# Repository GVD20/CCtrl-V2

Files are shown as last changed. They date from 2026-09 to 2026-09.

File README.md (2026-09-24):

<h1 align="center">CCtrl-V2</h1>

<p align="center">
  <strong>六轴机械臂关节空间遥操作器</strong><br>
  前两连杆等长 · 支持 XZY/ZXZ 腕部姿态表示
</p>

<p align="center">
  <a href="README.md">简体中文</a> · <a href="README_EN.md">English</a>
</p>

<p align="center">
  
  
  
</p>

<p align="center">
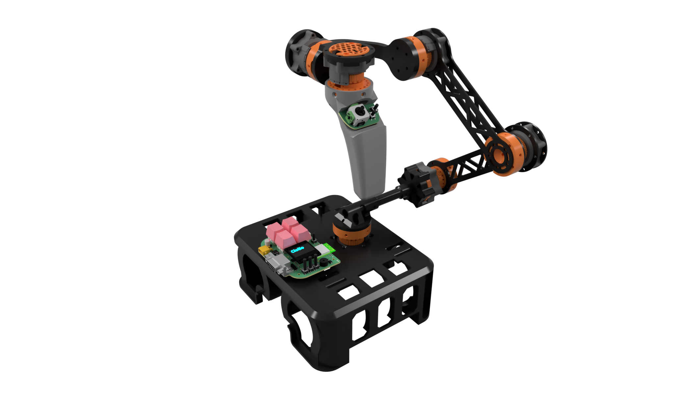
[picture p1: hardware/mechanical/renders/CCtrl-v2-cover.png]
CCtrl-V2 模型效果图
  
</p>

CCtrl-V2 以六个磁编码器采集 A1–A6 关节角，手柄节点采集摇杆、按键与磁感应扳机。ESP32-S3 主控负责节点轮询、校准、OLED 菜单、腕部姿态表示转换与 RS232 输出。本仓库包含嵌入式固件、四板 JLCEDA Pro 工程、机械模型、用户文档和调试工具。

<h5>▌快速入口</h5>

| 模块 | 中文 | English |
|---|---|---|
| 用户手册 | [CCtrl-v2_User_Manual_ZHCN](docs/CCtrl-v2_User_Manual_ZHCN.md) | [CCtrl-v2_User_Manual_EN](docs/CCtrl-v2_User_Manual_EN.md) |
| 嵌入式固件 | [CCtrl-v2_Embedded_Firmware_ZHCN](docs/CCtrl-v2_Embedded_Firmware_ZHCN.md) | [CCtrl-v2_Embedded_Firmware_EN](docs/CCtrl-v2_Embedded_Firmware_EN.md) |
| 硬件工程资料 | [CCtrl-v2_Hardware_Engineering_ZHCN](docs/CCtrl-v2_Hardware_Engineering_ZHCN.md) | [CCtrl-v2_Hardware_Engineering_EN](docs/CCtrl-v2_Hardware_Engineering_EN.md) |
| 机械模型 | [CCtrl-v2_Mechanical_Models_ZHCN](docs/CCtrl-v2_Mechanical_Models_ZHCN.md) | [CCtrl-v2_Mechanical_Models_EN](docs/CCtrl-v2_Mechanical_Models_EN.md) |
| 调试工具 | [CCtrl-v2_Debug_Tools_ZHCN](docs/CCtrl-v2_Debug_Tools_ZHCN.md) | [CCtrl-v2_Debug_Tools_EN](docs/CCtrl-v2_Debug_Tools_EN.md) |

专题文档：[节点协议](docs/PROTOCOL_V2.md) · [RS232 串口协议](docs/SERIAL_PROTOCOL_ZHCN.md) · [六轴校准](docs/CALIBRATION_ZHCN.md) · [USB 调试协议](docs/USB_DEBUG_ZHCN.md)

<h5>▌项目概览</h5>

- ESP32-S3 主板通过 250000 bps 菊花链串口连接六个 Encoder 节点与一个 Handle 节点；ATmega328P 与 CH32V006 提供节点固件实现。
- 六路 AS5600 编码器按物理链路顺序映射到 A1–A6。Handle 提供摇杆、S1–S3 按键和磁感应扳机，扳机行程生成 S4。
- RS232 约 30 Hz 输出固定 39 字节 RoboMaster `0x0302` 帧；USB CDC 用于手动启动的本地调试与校准。
- OLED 菜单提供六轴校准、休息位姿保护及腕部 XZY/ZXZ 表示选择。
- 控制端输出关节计数与状态；机械臂接收端实现目标机构的尺寸、零位、方向与运动控制映射。

<h5>▌与原版 CCtrl 的关系</h5>

本项目继承 [GVD20/CCtrl](https://github.com/GVD20/CCtrl) 的 MIT 许可、主板设计和 RoboMaster `0x0302` 外层帧，重构了机构构型、节点链路与载荷语义。

| 项目 | 原版 CCtrl | CCtrl-V2 |
|---|---|---|
| 机构与传感 | 三路编码器、IMU 的空间交互机构 | 面向前两段连杆等长机械臂的六关节编码器机构 |
| 节点链路 | 原版节点协议 | Daisy-Chain Protocol V2，支持 Encoder 与 Handle 节点 |
| 对外数据 | 融合位置、姿态与滚轮等数据 | 六关节计数、手柄输入及状态；[30 字节 V2 载荷](docs/SERIAL_PROTOCOL_ZHCN.md) |
| 上位机 | WebXR 等原版工作流 | RS232 通道监视器与本地 USB 调试校准页 |

两版共用 `0x0302` 命令号；接收端按对应版本的载荷格式解析。

<h5>▌目录结构</h5>

```text
.
├─ include/
├─ lib/
├─ src/
│  ├─ master/
│  ├─ node_avr/
│  ├─ node_ch32v006/
│  ├─ shared/
│  └─ ui_runtime/
├─ test/
├─ tools/
│  ├─ rs232_channel_monitor.py
│  └─ usb_robot_debug/
├─ docs/
├─ hardware/
│  ├─ electronics/jlc_eda_pro/
│  └─ mechanical/
├─ platformio.ini
├─ LICENSE
├─ README.md
└─ README_EN.md
```

<h5>▌固件构建</h5>

```bash
pio run -e master_esp32s3
pio run -e encoder_node_atmega328p
pio run -e encoder_node_ch32v006
```

CH32V006 节点按上电时检测到的传感器进入 Encoder 或 Handle 模式；ATmega328P 节点用于 Encoder。各环境的编程协议见[嵌入式固件](docs/CCtrl-v2_Embedded_Firmware_ZHCN.md)。

<h5>▌上位机与调试</h5>

```bash
python tools/rs232_channel_monitor.py
python tools/usb_robot_debug/server.py
```

- [RS232 通道监视器](tools/RS232_CHANNEL_MONITOR_ZHCN.md)：显示 39 字节业务帧中的六轴、状态、按键和手柄数据，并绘制曲线、导出 CSV。
- [USB 调试页面](tools/usb_robot_debug/README.md)：显示原始采样、XZY/ZXZ、诊断和校准配置；业务帧仍由 RS232 输出。

<h5>▌硬件资料</h5>

电子设计以包含主板、手柄模块 v2、带滑环的编码器节点板及滑环电刷的 [JLCEDA Pro 工程](hardware/electronics/jlc_eda_pro/CCtrl-v2.epro2)提供。机械资料包含[完整装配 STEP](hardware/mechanical/cad/CCtrl-v2-assembly.step)、[局部改进替换件 STEP](hardware/mechanical/cad/CCtrl-v2-replacement-parts.step)与透明封面图。

<h5>▌PIO 库依赖</h5>

- `encoder_node_atmega328p`：`robtillaart/AS5600`
- `master_esp32s3`：`frankboesing/FastCRC`、`olikraus/U8g2`
- 本地库：`lib/WouoUiLiteGeneralBridge`、`lib/WouoUiLiteGeneralOfficial`

<h5>▌验证</h5>

三个 PlatformIO 固件环境均完成构建；协议解析、休息位姿、腕部转换和 USB 帧解析通过源码测试。

<h5>▌UI 框架说明</h5>

项目 UI 实现参考并适配了 [RQNG/WouoUI](https://github.com/RQNG/WouoUI)。

<h5>▌开源协议</h5>

本项目采用 MIT License，详见 [LICENSE](LICENSE)。

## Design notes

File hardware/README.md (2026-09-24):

# CCtrl-V2 硬件资料

[用户手册](../docs/CCtrl-v2_User_Manual_ZHCN.md) · [返回首页](../README.md)

## 电子工程

[CCtrl-v2.epro2](electronics/jlc_eda_pro/CCtrl-v2.epro2) 是本版的 JLCEDA Pro 电子设计工程。包内包含主板、Handle_node_v2、Encoder_node_v3 和 Encoder_brush 四块板的原理图及 PCB 文档。主板延续原版主控方案；制造文件可在 JLCEDA Pro 中导出。

工程包含封装、引脚、电源、菊花链方向、滑环与电刷通道、板间连接等电子设计信息。

## 机械工程

[完整装配 STEP](mechanical/cad/CCtrl-v2-assembly.step) 提供整体模型；[替换件 STEP](mechanical/cad/CCtrl-v2-replacement-parts.step) 包含部分改进零件，用于替换完整模型中的对应零件。两份模型的关系见[机械说明](mechanical/README.md)。

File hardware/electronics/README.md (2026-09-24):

# 电子工程

[JLCEDA Pro 原生工程](jlc_eda_pro/CCtrl-v2.epro2)包含四块板：主板、手柄模块 v2、带滑环的编码器节点板，以及滑环电刷板。JLCEDA Pro 提供工程查看和制造文件导出功能。

主控、编码器和手柄固件入口见[用户手册](../../docs/CCtrl-v2_User_Manual_ZHCN.md)。原理图与 PCB 包含板层、器件、连接器、滑环走线和供电设计。

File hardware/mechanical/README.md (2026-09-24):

# 机械模型

| 文件 | 内容 |
|---|---|
| [CCtrl-v2-assembly.step](cad/CCtrl-v2-assembly.step) | 完整装配模型 |
| [CCtrl-v2-replacement-parts.step](cad/CCtrl-v2-replacement-parts.step) | 对主模型中部分零件的改进版本，涉及内部走线和稳定性 |
| [CCtrl-v2-cover.png](renders/CCtrl-v2-cover.png) | 带透明通道的效果图 |

替换件 STEP 用于更新完整装配中的部分零件。零件对应关系由两份 STEP 的几何形状与装配位置体现；封面图展示整体外观。结构说明见[机械模型](../../docs/CCtrl-v2_Mechanical_Models_ZHCN.md)。

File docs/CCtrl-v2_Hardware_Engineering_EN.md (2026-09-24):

# CCtrl-V2 Hardware Engineering

[ZHCN](CCtrl-v2_Hardware_Engineering_ZHCN.md) | [EN](CCtrl-v2_Hardware_Engineering_EN.md)

This page lists the CCtrl-V2 electronics project and its four board designs.

## Main files and directories

- [JLCEDA Pro project](../hardware/electronics/jlc_eda_pro/CCtrl-v2.epro2): schematic and PCB project.
- [Electronics guide](../hardware/electronics/README.md): project format and board list.
- [Hardware index](../hardware/README.md): electronics and mechanical assets.

## Project contents

| Board | Project name | Role |
|---|---|---|
| Main board | `CC_ESP32main` | ESP32-S3 master and external interfaces |
| Handle module v2 | `Handle_node_v2` | Joystick, buttons, magnetic trigger |
| Encoder node with slip ring | `Encoder_node_v3` | Joint-angle sampling and daisy-chain relay |
| Slip-ring brush | `Encoder_brush` | Electrical connection across a rotating joint |

The electronics are provided as a native JLCEDA Pro project, from which manufacturing outputs are exported. The main board retains the original CCtrl design basis; the nodes and handle match the six-axis mechanism and V2 firmware.

## Related documents

- [User manual](CCtrl-v2_User_Manual_EN.md)
- [Embedded firmware](CCtrl-v2_Embedded_Firmware_EN.md)
- [Mechanical models](CCtrl-v2_Mechanical_Models_EN.md)

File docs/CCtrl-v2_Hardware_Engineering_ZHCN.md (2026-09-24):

# CCtrl-V2 硬件工程资料

[ZHCN](CCtrl-v2_Hardware_Engineering_ZHCN.md) | [EN](CCtrl-v2_Hardware_Engineering_EN.md)

本页汇总 CCtrl-V2 的电子工程文件及四块板的项目组成。

## 主要文件与目录

- [JLCEDA Pro 工程](../hardware/electronics/jlc_eda_pro/CCtrl-v2.epro2)：原理图与 PCB 的项目文件。
- [电子工程说明](../hardware/electronics/README.md)：工程格式与板卡列表。
- [硬件资料入口](../hardware/README.md)：电子与机械资料目录。

## 工程组成

| 板卡 | 项目内名称 | 用途 |
|---|---|---|
| 主板 | `CC_ESP32main` | ESP32-S3 主控与对外接口 |
| 手柄模块 v2 | `Handle_node_v2` | 摇杆、按键与磁感应扳机 |
| 带滑环的编码器节点板 | `Encoder_node_v3` | 关节角采集与菊花链转发 |
| 滑环电刷 | `Encoder_brush` | 旋转关节的电气连接 |

电子设计以 JLCEDA Pro 原生项目提供，制造输出由该工程导出。主板沿用原版 CCtrl 的设计基础，节点与手柄对应六轴机构及 V2 固件。

## 相关文档

- [用户手册](CCtrl-v2_User_Manual_ZHCN.md)
- [嵌入式固件](CCtrl-v2_Embedded_Firmware_ZHCN.md)
- [机械模型](CCtrl-v2_Mechanical_Models_ZHCN.md)

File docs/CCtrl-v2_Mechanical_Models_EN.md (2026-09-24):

# CCtrl-V2 Mechanical Models

[ZHCN](CCtrl-v2_Mechanical_Models_ZHCN.md) | [EN](CCtrl-v2_Mechanical_Models_EN.md)

This page lists the CCtrl-V2 assembly model, improved replacement parts, and cover render.

## Main files and directories

| File | Contents |
|---|---|
| [CCtrl-v2-assembly.step](../hardware/mechanical/cad/CCtrl-v2-assembly.step) | Full assembly model |
| [CCtrl-v2-replacement-parts.step](../hardware/mechanical/cad/CCtrl-v2-replacement-parts.step) | Improved parts from the main model, including internal cable routing and stability changes |
| [CCtrl-v2-cover.png](../hardware/mechanical/renders/CCtrl-v2-cover.png) | Transparent-background cover render |
| [Mechanical assets guide](../hardware/mechanical/README.md) | Relationship between the model files |

## Model relationship

The full-assembly STEP describes the six-axis controller mechanism. The replacement-parts STEP contains revised versions of selected assembly parts; correspondence follows their geometry and position in the two STEP files. The cover PNG depicts the exterior and retains an alpha channel.

Joints A1–A6 correspond to the six Encoder channels, and the first two links are equal in length. The receiving robot controller maps joint counts to its own link dimensions and kinematics.

## Related documents

- [User manual](CCtrl-v2_User_Manual_EN.md)
- [Hardware engineering](CCtrl-v2_Hardware_Engineering_EN.md)

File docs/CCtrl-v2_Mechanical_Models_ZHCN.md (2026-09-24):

# CCtrl-V2 机械模型

[ZHCN](CCtrl-v2_Mechanical_Models_ZHCN.md) | [EN](CCtrl-v2_Mechanical_Models_EN.md)

本页汇总 CCtrl-V2 的机械装配、改进替换件及外观图。

## 主要文件与目录

| 文件 | 内容 |
|---|---|
| [CCtrl-v2-assembly.step](../hardware/mechanical/cad/CCtrl-v2-assembly.step) | 完整装配模型 |
| [CCtrl-v2-replacement-parts.step](../hardware/mechanical/cad/CCtrl-v2-replacement-parts.step) | 主模型中部分零件的改进版本，包含内走线与稳定性设计 |
| [CCtrl-v2-cover.png](../hardware/mechanical/renders/CCtrl-v2-cover.png) | 透明背景渲染主图 |
| [机械资料说明](../hardware/mechanical/README.md) | 模型文件关系 |

## 模型关系

完整装配 STEP 描述六轴控制器的整体结构。替换件 STEP 包含用于更新完整装配中对应零件的局部改进模型；替换关系由两份 STEP 的零件几何与装配位置确定。封面图展示外观，透明通道保留在 PNG 中。

控制器的关节 A1–A6 与六路 Encoder 数据对应，前两段连杆等长。接收端按目标机械臂的实际连杆尺寸建立运动学映射；控制器固件输出关节计数。

## 相关文档

- [用户手册](CCtrl-v2_User_Manual_ZHCN.md)
- [硬件工程资料](CCtrl-v2_Hardware_Engineering_ZHCN.md)

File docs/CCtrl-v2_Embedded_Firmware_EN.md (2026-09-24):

# CCtrl-V2 Embedded Firmware

[ZHCN](CCtrl-v2_Embedded_Firmware_ZHCN.md) | [EN](CCtrl-v2_Embedded_Firmware_EN.md)

This page maps the CCtrl-V2 firmware environments, source directories, and runtime roles.

## Main files and directories

| Entry | Contents |
|---|---|
| [platformio.ini](../platformio.ini) | Three PlatformIO environments, dependencies, upload protocols |
| [src/master](../src/master) | ESP32-S3 master, calibration, wrist conversion, USB debugging |
| [src/node_avr](../src/node_avr) | ATmega328P Encoder node |
| [src/node_ch32v006](../src/node_ch32v006) | CH32V006 Encoder/Handle node |
| [src/shared](../src/shared) | Daisy-chain frames, CRC, shared protocol definitions |
| [src/ui_runtime](../src/ui_runtime) | OLED UI runtime |
| [include](../include), [lib](../lib) | UI configuration, business interfaces, local libraries |
| [test](../test) | Protocol, rest-pose, and wrist-conversion tests |

## Build commands

| Environment | Hardware and role | Command |
|---|---|---|
| `master_esp32s3` | ESP32-S3 master | `pio run -e master_esp32s3` |
| `encoder_node_atmega328p` | 8 MHz ATmega328P Encoder | `pio run -e encoder_node_atmega328p` |
| `encoder_node_ch32v006` | CH32V006 Encoder/Handle | `pio run -e encoder_node_ch32v006` |

The configured upload protocols are esptool for the master, USBasp for ATmega328P, and WCH-Link for CH32V006. The PlatformIO upload target is `pio run -e <environment> -t upload`.

## Runtime structure

The master discovers and polls nodes over a 250000 bps daisy-chain link at about 45 Hz. RS232 emits a 39-byte frame at 115200 bps and about 30 Hz. CH32V006 selects Encoder or Handle mode from the sensor detected at startup; ATmega328P implements the Encoder role. Six-axis calibration, wrist representation, and rest-pose settings are stored in ESP32 NVS.

## Related documents

- [User manual](CCtrl-v2_User_Manual_EN.md)
- [Daisy-Chain Protocol V2](PROTOCOL_V2.md)
- [RS232 serial protocol](SERIAL_PROTOCOL_ZHCN.md)
- [Encoder calibration](CALIBRATION_ZHCN.md)

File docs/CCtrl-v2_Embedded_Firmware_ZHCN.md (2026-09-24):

# CCtrl-V2 嵌入式固件

[ZHCN](CCtrl-v2_Embedded_Firmware_ZHCN.md) | [EN](CCtrl-v2_Embedded_Firmware_EN.md)

本页汇总 CCtrl-V2 的固件环境、源码入口和运行职责。

## 主要文件与目录

| 入口 | 内容 |
|---|---|
| [platformio.ini](../platformio.ini) | 三个 PlatformIO 环境、依赖与编程协议 |
| [src/master](../src/master) | ESP32-S3 主控业务、校准、腕部转换、USB 调试 |
| [src/node_avr](../src/node_avr) | ATmega328P 编码器节点 |
| [src/node_ch32v006](../src/node_ch32v006) | CH32V006 Encoder/Handle 节点 |
| [src/shared](../src/shared) | 菊花链帧、CRC 与公共协议定义 |
| [src/ui_runtime](../src/ui_runtime) | OLED UI 运行入口 |
| [include](../include)、[lib](../lib) | UI 配置、业务接口与本地库 |
| [test](../test) | 协议、休息位姿与腕部表示测试 |

## 构建命令

| 环境 | 芯片与用途 | 命令 |
|---|---|---|
| `master_esp32s3` | ESP32-S3 主控 | `pio run -e master_esp32s3` |
| `encoder_node_atmega328p` | 8 MHz ATmega328P Encoder | `pio run -e encoder_node_atmega328p` |
| `encoder_node_ch32v006` | CH32V006 Encoder/Handle | `pio run -e encoder_node_ch32v006` |

配置中的主控编程协议为 esptool，ATmega328P 为 USBasp，CH32V006 为 WCH-Link。PlatformIO 上传目标为 `pio run -e <环境名> -t upload`。

## 运行结构

主控使用 250000 bps 菊花链链路枚举和轮询节点，约 45 Hz 收集采样。RS232 以 115200 bps、约 30 Hz 输出 39 字节业务帧。CH32V006 节点按上电时检测到的传感器进入 Encoder 或 Handle 模式；ATmega328P 环境实现 Encoder 节点。OLED 配置中的六轴校准、腕部表示和休息位姿写入 ESP32 NVS。

## 相关文档

- [用户手册](CCtrl-v2_User_Manual_ZHCN.md)
- [Daisy-Chain Protocol V2](PROTOCOL_V2.md)
- [RS232 串口协议](SERIAL_PROTOCOL_ZHCN.md)
- [六轴校准](CALIBRATION_ZHCN.md)

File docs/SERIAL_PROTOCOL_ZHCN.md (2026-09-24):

# CCtrl-v2 控制器串口协议说明

本文档描述 CCtrl-v2 ESP32-S3 主机向外部控制器输出的 RS232 二进制协议。

## 1. 串口参数与输出周期

| 项目 | 当前值 |
|---|---:|
| 物理接口 | RS232 |
| 波特率 | 115200 bps |
| 数据位 | 8 |
| 停止位 | 1 |
| 校验位 | 无 |
| 流控 | 无 |
| 输出周期 | 约30 Hz（33334 us，不超过 RM 30 Hz上限） |
| 数据方向 | ESP32-S3 主机向外部控制器单向输出 |

主机每个输出周期发送一帧。没有新的有效节点采样时，数值字段继续发送最近一次有效值；有效位和诊断字段反映当前状态。

启用上电休息位姿保护时，设备在确认物理姿态回到休息区域并连续稳定500 ms前，
六轴字段发送保存的标准休息位姿，系统状态为 `DEGRADED`。该功能不改变39字节
RS232帧格式；手动启动的USB调试通道同时提供的XZY和ZXZ双份数据不会加入
RS232帧。一般工作输出始终只使用RS232。

## 2. 完整帧

所有多字节整数均按小端顺序传输。

| 帧偏移 | 字段 | 类型 | 当前值或含义 |
|---:|---|---|---|
| 0 | `sof` | `uint8` | 固定 `0xA5` |
| 1–2 | `payload_len` | `uint16` | 固定 `30`，线上字节为 `1E 00` |
| 3 | `sequence` | `uint8` | 每帧加 1，`255` 后回到 `0` |
| 4 | `header_crc8` | `uint8` | 覆盖偏移 0–3 |
| 5–6 | `cmd_id` | `uint16` | 固定 `0x0302`，线上字节为 `02 03` |
| 7–36 | `payload` | 30 bytes | CCtrl 当前业务数据，符合 RM `0x0302` 固定长度 |
| 37–38 | `frame_crc16` | `uint16` | 覆盖偏移 0–36 |

完整帧固定为39字节。RoboMaster 帧头中的 `payload_len` 只表示 `data` 长度，
不包含2字节 `cmd_id`；因此 `0x0302` 的 data 固定为30字节。

## 3. Payload

下表的偏移以30字节 payload 的第一个字节为0；换算为完整帧偏移时加7。

| Payload 偏移 | 字段 | 类型 | 可用值 |
|---:|---|---|---|
| 0 | `diagnostic_flags` | `uint8` | 系统状态、错误和警告的组合位 |
| 1 | `node_valid_flags` | `uint8` | 六路 Encoder 与 Handle 的当前有效位 |
| 2 | `main_buttons` | `uint8` | ESP32 主机快捷键的单击/双击事件 |
| 3 | `handle_buttons` | `uint8` | Handle 的 S1–S4 |
| 4–9 | `encoder_status[6]` | `uint8[6]` | A1–A6 节点状态 |
| 10–21 | `encoder_value[6]` | `int16[6]` | A1–A6 校准后的有符号位置计数 |
| 22–23 | `joystick_x` | `uint16` | Handle 摇杆 X 行程 |
| 24–25 | `joystick_y` | `uint16` | Handle 摇杆 Y 行程，方向已在主机中反转 |
| 26–27 | `trigger` | `uint16` | Handle 扳机行程 |
| 28–29 | `reserved` | `uint16` | 保留，当前发送 `0` |

### 3.1 diagnostic_flags

| 位 | 名称 | 含义 |
|---:|---|---|
| bit0–1 | `system_status` | `0 INIT`、`1 ACTIVE`、`2 DEGRADED`、`3 DISCONNECTED` |
| bit2 | `timeout_error` | `1` 表示 500 ms 内没有收到协议与 CRC 均正确的有效菊花链帧 |
| bit3 | `crc_warning` | `1` 表示最近 2 秒检测过菊花链 CRC 错误 |
| bit4 | `format_warning` | `1` 表示最近 2 秒检测过不符合协议的数据格式 |
| bit5 | `magnet_warning` | `1` 表示最近 2 秒检测过 Encoder 磁场异常或未检测到磁铁 |
| bit6 | `node_count_warning` | `1` 表示最近 2 秒 POLL 节点数量与上次成功枚举不一致 |
| bit7 | 保留 | 当前为 `0` |

字段拆分方式：

```text
system_status  = diagnostic_flags & 0x03
timeout_error  = (diagnostic_flags >> 2) & 0x01
warning_flags  = (diagnostic_flags >> 3) & 0x0F
```

### 3.2 node_valid_flags

| 位 | 对应数据 |
|---:|---|
| bit0–bit5 | A1–A6 Encoder |
| bit6 | Handle |
| bit7 | 保留 |

某个 Encoder 位为 `1` 时，对应的 `encoder_status[n]` 和 `encoder_value[n]` 是当前有效数据。位为 `0` 时，`encoder_value[n]` 可能仍保留最近一次有效值；从未收到有效值时为 `0`。

Handle bit6 为 `1` 时，`handle_buttons`、`joystick_x`、`joystick_y` 和 `trigger` 是当前有效数据。Handle 缺失或尚未获得有效采样时该位为 `0`。

### 3.3 按键

`main_buttons`：

| 位 | 含义 |
|---:|---|
| bit0–bit3 | KEY1–KEY4单击事件 |
| bit4–bit7 | KEY1–KEY4双击事件，分别对外表示KEY5–KEY8 |

KEY1–KEY4先经过20ms软件去抖。非磁贴菜单模式下，第一次有效按下开启300ms双击窗口；窗口超时才发送对应低位单击，窗口内第二次有效按下则立即发送对应高位双击且不会发送低位。事件位持续160ms，判定后同一物理按键进入200ms不应期，期间不响应也不发声。磁贴菜单模式保持原电平行为，只直接使用bit0–bit3。

主机上的三个菜单导航键不进入 `main_buttons`。

`handle_buttons`：

| 位 | 含义 |
|---:|---|
| bit0 | S1；按下为 `1` |
| bit1 | S2；按下为 `1` |
| bit2 | S3，摇杆按键；按下为 `1` |
| bit3 | S4，扳机数字状态；按下为 `1` |
| bit4–bit7 | 保留 |

S4 在扳机行程达到 80% 时置位，并保持到行程低于 50% 时清除。

### 3.4 Encoder 状态

每个 `encoder_status[n]` 使用以下位：

| 位 | 含义 |
|---:|---|
| bit0 | AS5600 I2C 通讯正常 |
| bit1 | 检测到磁铁 |
| bit2 | 磁场过弱 |
| bit3 | 磁场过强 |
| bit4 | 数据过期 |
| bit5–bit7 | 保留 |

当前正常且检测到磁铁时数值为 `0x03`。

### 3.5 Encoder 数值口径

`encoder_value[0]` 到 `encoder_value[5]` 对应 A1 到 A6。每路均为主机校准后的 `int16` 有符号计数，范围为 `-2048` 到 `2047`，一圈为 4096 计数：

```text
角度（度） = encoder_value * 360 / 4096
角度（弧度） = encoder_value * 2π / 4096
```

方向已经使用主机保存的逐轴 `direction` 配置处理。执行主机的六轴置零后，A1、A4、A5、A6 的当前位置输出为 0；A2 的当前位置输出为约 `+20°`（228 计数），A3 的当前位置输出为约 `+60°`（683 计数）。环形折返点位于 `-2048/2047`。

主机菜单 `Options -> Wrist` 为 `XZY` 时，A4、A5、A6 分别直接输出校准后的 X、Z、Y 角。设置为 `ZXZ` 时，转换输入与配套网页一致，先按 `X=-A4, Z=A5, Y=-A6` 组成右手系内禀主动旋转
`R = Rx(-A4) · Rz(A5) · Ry(-A6)`，再将同一姿态转换为
`R = Rz(α) · Rx(β) · Rz(γ)`，并依次通过 A4、A5、A6 输出。ZXZ 模式只改变 A4–A6 的对外输出，不改变节点采集值或保存的逐轴校准值。该选项保存在 ESP32 NVS 中。

ZXZ 的 `β=0°` 和 `β=180°` 附近为欧拉角奇异区。当前固件在距奇异点 3° 内进入连续跟随，保持可观测的 `α+γ` 或 `α−γ`，并将变化平均分配给两个 Z 轴；距奇异点达到 5°后退出。退出时按每个30 Hz输出帧、每轴最多9°逐步恢复精确解。常规区从两个等价 ZXZ 解中选择最接近上一帧的分支。

### 3.6 Handle 模拟量

| 字段 | 范围 | 中心或端点 |
|---|---:|---|
| `joystick_x` | 0–4095 | 中心 2048，已包含中央死区 |
| `joystick_y` | 0–4095 | 中心 2048，已包含中央死区，输出方向已反转 |
| `trigger` | 0–4095 | 0 为完全松开，4095 为完全按下，端点包含死区 |

百分比换算为：`value * 100 / 4095`。

## 4. CRC 算法

Header CRC8 的初值为 `0xFF`，反射多项式为 `0x8C`。Frame CRC16 的初值为 `0xFFFF`，反射多项式为 `0x8408`。CRC16 结果以小端顺序放在帧尾。

```c
uint8_t cctrl_crc8(const uint8_t *data, size_t length) {
    uint8_t value = 0xFF;
    while (length--) {
        value ^= *data++;
        for (uint8_t i = 0; i < 8; ++i)
            value = (value >> 1) ^ ((value & 1) ? 0x8C : 0);
    }
    return value;
}

uint16_t cctrl_crc16(const uint8_t *data, size_t length) {
    uint16_t value = 0xFFFF;
    while (length--) {
        value ^= *data++;
        for (uint8_t i = 0; i < 8; ++i)
            value = (value >> 1) ^ ((value & 1) ? 0x8408 : 0);
    }
    return value;
}
```

## 5. 参考解析流程

仓库中的 [`tools/protocol_v2.py`](../tools/protocol_v2.py) 按以下顺序解析字节流：

1. 定位 `0xA5`，读取前 5 字节中的小端 `payload_len`，并匹配固定值 `30`。
2. 收齐 39 字节后，比较偏移 0–3 的 CRC8 与偏移 4 的值。
3. 比较偏移 5–6 的小端命令号与 `0x0302`，并验证偏移 0–36 的 CRC16。
4. 按第 3 节的字段表解析 payload，返回带 `sequence` 的 `HostFrame` 供上层统计。
5. CRC 或格式校验失败的候选帧被丢弃，解析器从后续字节继续搜索 `0xA5`。

## 6. 示例帧

以下示例的 `sequence=0`，系统状态为 ACTIVE，A1–A6 全部正常，六轴值依次为 `0, 228, 683, -1, 2047, -2048`，摇杆居中，扳机为 4095：

```text
A5 1E 00 00 7D 02 03 01 7F 03 05 03 03 03 03 03 03 00 00 E4 00 AB 02 FF FF FF 07 00 F8 00 08 00 08 FF 0F 00 00 57 39
```

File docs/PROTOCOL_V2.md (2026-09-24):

# Daisy-Chain Protocol V2

## 总线

总线速率 250000 bps，ESP32-S3 以 45 Hz 轮询。所有多字节字段均为小端。
主机向 RS232 上位机的 RoboMaster `0x0302` 输出独立固定为30 Hz。USB只承载手动
启动的调试协议，不承载一般业务帧。

`main_buttons`低4位表示KEY1–KEY4单击，高4位表示相同物理键的双击
（对外命名KEY5–KEY8）。快捷键使用20ms去抖、300ms双击窗口、160ms事件脉冲和
200ms同键不应期；双击不会同时产生单击位。三个菜单导航键不进入主机帧。

帧头为 8 字节：`sof(0xC65A), version(2), message_type, sequence,
node_count, payload_len, flags`，随后为 payload 和 RoboMaster CRC16。CRC16 覆盖
帧头与 payload，完整帧不超过 96 字节。

消息类型只有：

- `0x01 ENUM_RESET`：清除地址并按物理链路顺序枚举。
- `0x02 POLL`：逐节点追加采样记录。

节点完整收帧并校验 CRC，CRC 错误时丢弃该帧；CRC 正确、消息类型未识别的帧
保持原样传给下游。链路超时由主控判断。

节点记录头为 `node_id, node_type, platform, data_len`。`node_type` 中 Encoder=1、
Handle=2；`platform` 中 ATmega328P=1、CH32V006=2。

- 枚举数据：`fw_major, fw_minor, capabilities(uint16)`。
- Encoder：`status_flags, raw_angle(uint16)`，数据长度 3。
- Handle：`status_flags, joystick_x(uint16), joystick_y(uint16),
  magnetic_x(int16), magnetic_y(int16), magnetic_z(int16), buttons(uint8)`，数据长度 12。

Encoder 状态位：bit0 I2C 正常、bit1 检测到磁场、bit2 磁场过弱、bit3 磁场
过强、bit4 数据过期。Encoder slot 只按枚举结果中 Encoder 出现的次序生成，Handle
插入任意位置均不改变 Encoder 映射。

Handle 状态位：bit0 I2C 正常、bit1 TMAG 数据有效、bit2 数据过期。节点记录中的
`buttons` bit0/1/2 分别为 S1/S2/S3。ESP32 根据 TMAG XYZ 轨迹计算 0–4095 扳机
行程。行程达到 80%（计数不低于 3276）时将 `handle_buttons` bit3 置位为虚拟
S4，并保持到行程低于 50%（计数低于 2048）再清除。

## 主机诊断

主机内部错误位包括 `bit0 = 500 ms 内没有收到协议和 CRC 都正确的有效帧`，以及 `bit1 = 上电休息位姿保护尚未解除`。对外 RS232 的 `diagnostic_flags.bit2` 只编码链路超时；休息位姿保护通过 `DEGRADED` 状态表示，详细标志可从 USB 调试通道读取。

警告在最后一次发现对应问题后保持 2 秒：

| 位 | 含义 |
|---:|---|
| bit0 | CRC 校验失败 |
| bit1 | 帧头、消息类型或节点记录格式不符合协议 |
| bit2 | Encoder 磁场弱、强或未检测到磁铁 |
| bit3 | POLL 节点数量与最近一次成功枚举不一致 |

节点数量警告在 POLL 与最近一次成功枚举的节点数量不一致时触发。主机根据
连续有效 POLL 的 sequence 差值累计丢失帧数，重复或迟到的旧帧不重复计数。

## 上位机

保留 RoboMaster 外层：`0xA5 + payload_len + seq + header_crc8 + cmd_id +
payload + crc16`。命令为 `0x0302`，`payload_len` 按 RM 定义只计算 data，固定
为30字节；完整帧为39字节：

| 偏移 | 字段 | 类型 |
|---:|---|---|
| 0 | diagnostic_flags | uint8 |
| 1 | node_valid_flags | uint8 |
| 2 | ESP32 四按键 | uint8 |
| 3 | Handle 四按键 | uint8 |
| 4 | 六路 Encoder 状态 | uint8[6] |
| 10 | 六路校准后有符号计数 | int16[6] |
| 22 | joystick X | uint16 |
| 24 | joystick Y | uint16 |
| 26 | 扳机行程 | uint16 |
| 28 | 保留，当前为0 | uint16 |

`diagnostic_flags` 的 bit0–1 为 system_status，bit2 为 timeout error，bit3–6
依次为 CRC、格式、磁场、节点数量警告，bit7 保留。命令号 `0x0302` 标识
RoboMaster 外层帧；CCtrl-v2 使用本节的 30 字节 payload 布局。system_status：
0 INIT、1 ACTIVE、2 DEGRADED、3 DISCONNECTED。`node_valid_flags` bit0–5
对应六路 Encoder，bit6 对应 Handle。无效 Encoder 保留最后值并清除有效位；
Handle 采样仅在记录存在、状态有效且 XYZ 不是全零时更新。暂时缺少新有效采样、
链路超时或收到坏帧时，模拟量与按键继续输出最后一次有效值，同时通过有效位和
诊断字段反映当前链路状态，不再注入临时零值。固定载荷长度为30字节，末尾2字节
为保留字段且当前发送0。参考实现
位于 `tools/protocol_v2.py`。

六路 Encoder 的置零位置为有符号 0，输出范围为 -2048–2047。经过置零位置时数值
连续穿过 0；模 4096 的折返点位于零位正对面的 -2048/2047 边界。

`Options -> Wrist` 可在 XZY 与 ZXZ 末端轴系之间切换并保存到 NVS。XZY 模式直接
输出 A4/A5/A6 的 X/Z/Y 校准角；ZXZ 模式按右手系内禀主动旋转
`Rx(-A4)·Rz(A5)·Ry(-A6) = Rz(alpha)·Rx(beta)·Rz(gamma)` 转换最终三个
输出值，采用配套网页相同的 `X=-A4, Z=A5, Y=-A6` 方向约定。
`beta=0°/180°` 奇异点 3° 内进入连续跟随，达到 5°后退出；退出时每个30 Hz
输出帧每轴最多恢复9°。常规区选择与上一帧最接近的等价 ZXZ 分支。

Joystick X/Y 由 ESP32 对 Handle 原始 ADC 值进行分段线性校准，统一输出 0–4095，
中心为 2048。X 使用原始范围 805/2010/3226，Y 使用 857/1985/3150；两个轴在
中心两侧各保留 50 个原始 ADC 码的死区。Y 轴在校准后反向输出，X 轴方向不变。

S1–S4 任一按键从松开变为按下时，ESP32 主机播放一次按键提示音；持续按住不会
重复触发。S4 在扳机降到 50% 以下而解除时，另播放一次较低音调的退出提示音。

## 节点 LED

Encoder 的 STAT 和 ERR 上电同时闪两次；识别为 Handle 时，ERR 和 STAT 上电各闪
两次且交替出现，用于直接确认自动识别结果。枚举后，STAT 每 5 秒按用户可见编号
闪烁 `node_id+1` 次。Handle 任一按键按下时 STAT 立即点亮，保持到松开且每次至少
点亮 200 ms；按键显示优先于其他灯效。ERR 闪烁次数：1=未检测到磁铁、2=磁场弱、
3=磁场强、4=最近 2 秒发生 CRC 丢帧、5=I2C 设备不可用。

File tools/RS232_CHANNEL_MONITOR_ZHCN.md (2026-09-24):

# CCtrl RS232 通道监视器

轻量桌面工具，用于接收 ESP32-S3 主机在 RS232 上输出的 Protocol V2
RoboMaster `0x0302` 二进制帧。

## 启动

```powershell
python tools/rs232_channel_monitor.py
```

也可以直接双击 `tools/start_rs232_channel_monitor.bat`。

依赖 Python 3、Tkinter 和 pyserial。安装 pyserial：

```powershell
python -m pip install pyserial
```

## 使用

1. 在顶部选择 RS232 对应的 COM 口并点击“连接”。串口固定使用 115200 8N1。
2. 左侧显示当前所有通道值。勾选任意一个或多个通道即可绘制曲线。
3. 默认启用“友好值”：Encoder 显示带正负号的角度，Joystick 与 Trigger 显示
   0–100% 行程，状态位和按键显示具体含义。关闭后恢复协议原始整数/十六进制值。
4. “曲线窗口”可选择最近 5–600 秒。修改窗口不会丢失已采集数据。
5. 数值范围差异很大时，可启用“各通道独立缩放”观察每条曲线的相对变化。
6. “暂停曲线”会冻结当前时间窗口，但串口仍在后台采集。暂停后可以切换通道、
   缩放和导出；点击“继续曲线”后回到最新数据，暂停期间的数据不会丢失。
7. “导出当前窗口”只导出当前时间窗内、当前已勾选的通道，CSV 包含本地时间、
   相对时间和帧序号。为保证后续标定和复现，CSV 始终保存协议原始数值，不受
   “友好值”开关影响。
8. “清空历史”会同时清零当前连接的接收帧数、坏帧数和序号缺失统计。

Handle 的三个 TMAG 原始通道已由 ESP32 内部拟合为 0–4095 的 `Trigger` 通道；
工具显示和导出的也是该扳机行程。

工具会在任意字节位置重新寻找 `0xA5` 帧头，并验证 Header CRC8、命令号、30 字节
载荷长度和整帧 CRC16。串口中途连接、半帧和坏帧不会让后续数据显示错位。

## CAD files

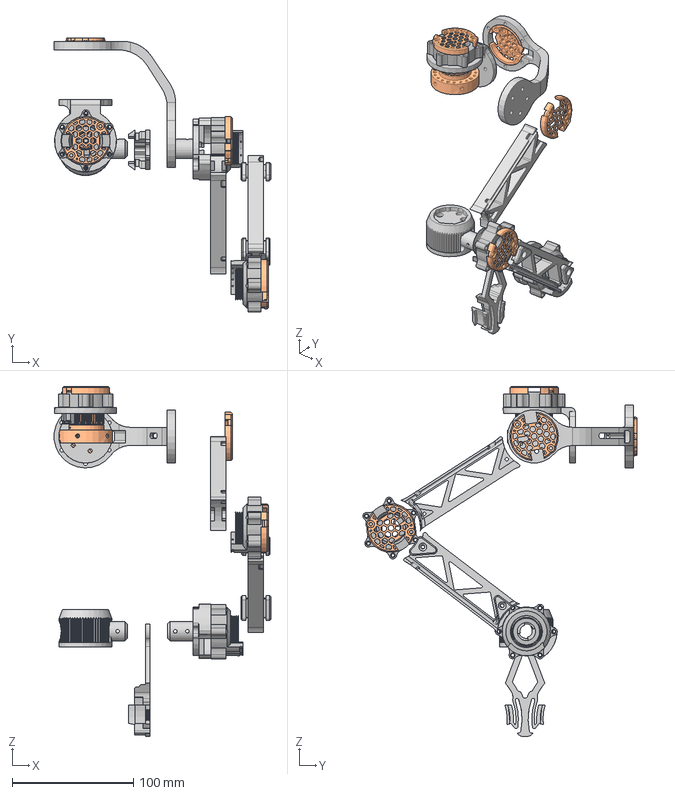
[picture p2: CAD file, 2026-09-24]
hardware/mechanical/cad/CCtrl-v2-replacement-parts.step
178.5 x 226.0 x 288.4 mm
node111_1
node111_2
node111_3
node111_4
node111_5

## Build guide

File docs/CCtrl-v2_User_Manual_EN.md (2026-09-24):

# CCtrl-V2 User Manual

[ZHCN](CCtrl-v2_User_Manual_ZHCN.md) | [EN](CCtrl-v2_User_Manual_EN.md)

This manual describes the controller, firmware, communication links, output data, device settings, and tools. The [serial protocol](SERIAL_PROTOCOL_ZHCN.md) contains the complete byte layout; [Daisy-Chain Protocol V2](PROTOCOL_V2.md) defines the node link.

## 1. Project definition

CCtrl-V2 is a joint-space teleoperation controller for a six-degree-of-freedom serial robot arm with equal-length first and second links. Six magnetic encoders measure joints A1–A6. A handle node measures a joystick, S1–S3 buttons, and a magnetic trigger. The ESP32-S3 master handles node discovery and polling, calibration, the OLED menu, wrist-orientation representation, and output.

The controller outputs joint counts, handle inputs, and link status. The receiving robot controller implements its own geometry, joint zero positions, drive ratios, kinematics, and motor control.

| Component | Implementation | Data or role |
|---|---|---|
| Master | ESP32-S3 board | Calibration, menu, node polling, output |
| Joint nodes | Six AS5600 encoder nodes | Magnet status and raw angle, 4096 counts per revolution |
| Handle node | Handle module | Joystick, buttons, magnetic XYZ |
| External interface | RS232 | RoboMaster `0x0302` frame at about 30 Hz |
| Local debug interface | USB CDC | Manually enabled calibration and status snapshots |

## 2. Firmware and runtime structure

- [`src/master`](../src/master): ESP32-S3 polling, calibration, RS232, and USB debugging.
- [`src/node_avr`](../src/node_avr): ATmega328P encoder-node firmware.
- [`src/node_ch32v006`](../src/node_ch32v006): CH32V006 firmware, selecting Encoder or Handle mode from the detected sensor at startup.
- [`src/shared`](../src/shared): Daisy-Chain Protocol V2 and CRC code.
- [`src/ui_runtime`](../src/ui_runtime), [`include`](../include), [`lib`](../lib): OLED UI, shared interfaces, and local libraries.

The physical order of Encoder nodes defines A1–A6. The Handle has separate output fields and can occupy a position between Encoder nodes. The node-poll period is about 22.2 ms; the external-frame period is about 33.3 ms.

## 3. Communication links

### 3.1 External link

RS232 sends business frames from the ESP32-S3 to the receiving controller at 115200 bps, 8N1. A frame contains the `0xA5` header, length, sequence, CRC8, command ID `0x0302`, a 30-byte payload, and CRC16. Its total length is 39 bytes. USB debugging uses a separate channel.

### 3.2 Master and node link

The daisy-chain UART runs at 250000 bps. `ENUM_RESET (0x01)` assigns addresses in physical order; `POLL (0x02)` collects node records. An Encoder record contains status and raw angle. A Handle record contains joystick, magnetic XYZ, and buttons. See the [node protocol](PROTOCOL_V2.md) for framing, status bits, and LED behavior.

### 3.3 USB debug link

USB CDC is disabled at startup. `USB Debug → Start Debug` on the OLED menu enables the `CCtrl USB Debug` serial device, which the web page opens at 2000000 baud. The master sends raw-axis, XZY, ZXZ, diagnostic, and configuration snapshots at about 15 Hz. USB CDC remains enabled until reboot, while RS232 continues to carry business frames. The [USB debug protocol](USB_DEBUG_ZHCN.md) lists frame types and commands.

## 4. Unified output protocol (`0x0302`)

### 4.1 Frame structure

```text
SOF(0xA5) + data_length(2) + sequence(1) + CRC8(1)
+ cmd_id(0x0302, 2) + payload(30) + CRC16(2)
```

Multibyte integers use little-endian order. `data_length` is 30; the one-byte `sequence` increments modulo 256.

### 4.2 The 30-byte payload

| Offset | Length | Field | Type | Meaning |
|---:|---:|---|---|---|
| 0 | 1 | `diagnostic_flags` | `uint8` | System state, timeout, warnings |
| 1 | 1 | `node_valid_flags` | `uint8` | A1–A6 and Handle validity |
| 2 | 1 | `main_buttons` | `uint8` | KEY1–KEY4 single and double clicks |
| 3 | 1 | `handle_buttons` | `uint8` | S1–S4 states |
| 4–9 | 6 | `encoder_status[6]` | `uint8[6]` | Encoder sample states |
| 10–21 | 12 | `encoder_value[6]` | `int16[6]` | Calibrated joint counts |
| 22–27 | 6 | `joystick_x/y`, `trigger` | `uint16[3]` | Handle analog values, 0–4095 |
| 28–29 | 2 | `reserved` | `uint16` | Currently zero |

### 4.3 Status and validity

Bits 0–1 of `diagnostic_flags` encode `INIT`, `ACTIVE`, `DEGRADED`, or `DISCONNECTED`. Bit 2 marks link timeout; bits 3–6 mark CRC, format, magnet, and node-count warnings. Bits 0–5 of `node_valid_flags` correspond to A1–A6, and bit 6 to the Handle. During a sampling interruption, value fields retain their latest valid samples while validity and diagnostic fields report current state.

### 4.4 Joint counts

Each calibrated joint value ranges from `-2048` to `2047`, with 4096 counts per revolution. Degrees equal `encoder_value × 360 / 4096`. The circular wrap lies opposite the calibrated zero at `2047/-2048`. In `encoder_status`, bit 0 indicates I2C communication, bit 1 magnet detection, bits 2–3 weak or strong magnetic field, and bit 4 stale data. Status `0x03` indicates normal communication and magnet detection.

The [serial protocol](SERIAL_PROTOCOL_ZHCN.md) provides byte offsets, CRC algorithms, and a sample frame. Both CCtrl generations use command ID `0x0302`; CCtrl-V2 uses the payload layout above.

## 5. Output semantics

### 5.1 Joints and wrist

A1–A3 describe the main joints; A4–A6 describe the wrist. `Options → Wrist` selects `XZY`, which outputs calibrated A4–A6 directly, or `ZXZ`, which expresses the same wrist orientation in another Euler-angle convention. The conversion uses `Rx(-A4)·Rz(A5)·Ry(-A6) = Rz(α)·Rx(β)·Rz(γ)`. Near β=0° and β=180°, the firmware tracks a continuous solution branch. The selection is stored in NVS.

### 5.2 Buttons and analog inputs

The low four bits of `main_buttons` represent KEY1–KEY4 single-click events; the high four bits represent their double-click events. The firmware uses 20 ms debounce, a 300 ms double-click window, a 160 ms event pulse, and a 200 ms same-key refractory period. Handle bits 0–2 represent S1–S3. Bit 3 represents virtual S4, set at 80% trigger travel and cleared below 50%.

Joystick X/Y and trigger values range from 0 to 4095. The joystick center is 2048. The master maps raw ADC samples piecewise and reverses the Y output. The measured constants appear in [Handle joystick calibration](JOYSTICK_CALIBRATION_ZHCN.md).

### 5.3 Startup rest pose

`Options → RestGuard` stores the protection setting for the next startup. When enabled, RS232 emits the stored standard rest pose with `DEGRADED` status until all six joints enter the stored region for 500 ms. A1, A5, and A6 use ±30° entry and ±35° exit thresholds; A2–A4 use ±2° and ±3°. The USB page stores the current healthy, fresh raw samples as the rest pose.

## 6. Device settings and calibration

The OLED `Calibration → Encoder_calibration` menu contains `Zero All 6`, A1–A6 `Reverse`, `Save`, and `Reload`. `Zero All 6` captures the current raw samples and assigns 0° to A1 and A4–A6, +20° (about 228 counts) to A2, and +60° (about 683 counts) to A3. The operation writes the complete calibration set to NVS when all six nodes are present, I2C communication works, and magnets are detected.

Calibration contains six offsets and directions in a versioned NVS blob with CRC16. The USB page displays raw counts, offsets, directions, and calibrated angles. It offers 0°, ±90°, 180°, and custom targets, saving all six axes as one revisioned, CRC-protected transaction. The calculation is documented in [Encoder calibration](CALIBRATION_ZHCN.md).

## 7. Host tools

- [RS232 channel monitor](../tools/RS232_CHANNEL_MONITOR_ZHCN.md): `python tools/rs232_channel_monitor.py`; displays decoded fields and plots and exports raw-value CSV data.
- [USB Web Serial debugger](../tools/usb_robot_debug/README.md): `python tools/usb_robot_debug/server.py`; serves the local page at `http://127.0.0.1:8768` for raw axes, XZY/ZXZ, diagnostics, calibration, and rest pose.
- [Protocol parser](../tools/protocol_v2.py): Python reference parser and CRC implementation for RS232 frames.

The [debug tools index](CCtrl-v2_Debug_Tools_EN.md) lists these entries and their functions.

## 8. Build and upload

[`platformio.ini`](../platformio.ini) defines three environments:

| Environment | Hardware | Programmer | Build command |
|---|---|---|---|
| `master_esp32s3` | ESP32-S3 master | esptool | `pio run -e master_esp32s3` |
| `encoder_node_atmega328p` | 8 MHz ATmega328P Encoder | USBasp | `pio run -e encoder_node_atmega328p` |
| `encoder_node_ch32v006` | CH32V006 node | WCH-Link | `pio run -e encoder_node_ch32v006` |

The PlatformIO upload target is `pio run -e <environment> -t upload`. The [firmware index](CCtrl-v2_Embedded_Firmware_EN.md) maps files and runtime responsibilities.

## 9. Project assets and verification

- [Hardware engineering](CCtrl-v2_Hardware_Engineering_EN.md): the four-board JLCEDA Pro project.
- [Mechanical models](CCtrl-v2_Mechanical_Models_EN.md): assembly STEP, improved replacement-parts STEP, and transparent cover image.
- [Node protocol](PROTOCOL_V2.md): enumeration, polling, records, status, and LEDs.
- [External serial protocol](SERIAL_PROTOCOL_ZHCN.md): 39-byte frame, 30-byte payload, and byte definitions.

All three PlatformIO firmware environments have built successfully. The 12 protocol tests, C++ rest-pose and wrist-conversion tests, and USB frame-parser self-test have passed.

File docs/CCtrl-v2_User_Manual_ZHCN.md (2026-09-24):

# CCtrl-V2 用户手册

[ZHCN](CCtrl-v2_User_Manual_ZHCN.md) | [EN](CCtrl-v2_User_Manual_EN.md)

本文档描述 CCtrl-V2 的组成、运行结构、通信数据、设备配置和工具入口。字段的完整字节定义见[串口协议](SERIAL_PROTOCOL_ZHCN.md)，节点链路定义见[Daisy-Chain Protocol V2](PROTOCOL_V2.md)。

## 1. 项目定义

CCtrl-V2 是面向前两段连杆等长的六自由度串联机械臂的关节空间遥操作控制器。六个磁编码器采集 A1–A6 关节位置；手柄节点采集摇杆、S1–S3 按键和磁感应扳机。ESP32-S3 主控完成节点枚举与轮询、校准、OLED 显示、腕部姿态表示转换和对外输出。

系统输出的是控制器关节计数、输入设备数据和链路状态。目标机械臂的连杆尺寸、关节零位、传动比例、运动学和电机控制由机械臂接收端实现。

| 组成 | 实现 | 数据 |
|---|---|---|
| 主控 | ESP32-S3 主板 | 六轴校准值、菜单与输出状态 |
| 关节节点 | 六个 AS5600 编码器节点 | 磁场状态与一圈 4096 计数的原始角度 |
| 手柄节点 | Handle 模块 | 摇杆、按键和磁场 XYZ |
| 对外接口 | RS232 | 约 30 Hz 的 RoboMaster `0x0302` 帧 |
| 本地调试接口 | USB CDC | 手动启动的校准与状态快照 |

## 2. 固件与运行结构

- [`src/master`](../src/master)：ESP32-S3 的总线轮询、数据整合、校准、RS232 和 USB 调试实现。
- [`src/node_avr`](../src/node_avr)：ATmega328P 编码器节点固件。
- [`src/node_ch32v006`](../src/node_ch32v006)：CH32V006 节点固件，上电后按检测到的传感器进入 Encoder 或 Handle 模式。
- [`src/shared`](../src/shared)：Daisy-Chain Protocol V2 与 CRC 公共实现。
- [`src/ui_runtime`](../src/ui_runtime)、[`include`](../include)、[`lib`](../lib)：OLED UI、公共接口和本地库。

主控按物理链路顺序枚举节点。Encoder 出现的先后顺序映射为 A1–A6；Handle 有独立的数据字段，处于编码器节点之间时也不改变轴号。总线轮询周期约 22.2 ms，业务帧输出周期约 33.3 ms。

## 3. 通信链路

### 3.1 对外链路

ESP32-S3 通过 RS232 以 115200 bps、8N1 向外部控制器单向输出业务帧。帧由 `0xA5` 帧头、长度、序号、CRC8、命令号 `0x0302`、30 字节载荷和 CRC16 组成，总长 39 字节。RS232 输出与 USB 调试各自使用独立的数据通道。

### 3.2 主控与节点链路

主控与节点之间的菊花链串口速率为 250000 bps。`ENUM_RESET (0x01)` 根据物理顺序分配地址，`POLL (0x02)` 逐节点收集记录。节点记录包含 ID、类型、平台和节点数据；Encoder 提供状态与原始角度，Handle 提供摇杆、磁场 XYZ 与按键。帧格式、节点状态位和 LED 行为见[节点协议](PROTOCOL_V2.md)。

### 3.3 USB 调试链路

USB CDC 上电时处于关闭状态。OLED 主菜单的 `USB Debug → Start Debug` 启动串口，设备名为 `CCtrl USB Debug`，网页以 2000000 baud 连接。主控约 15 Hz 发送原始六轴、XZY、ZXZ、诊断与配置快照。USB 调试串口保持开启至设备重启；业务帧继续通过 RS232 输出。[USB 调试协议](USB_DEBUG_ZHCN.md)列出帧类型与配置命令。

## 4. 统一输出协议（0x0302）

### 4.1 帧结构

```text
SOF(0xA5) + data_length(2) + sequence(1) + CRC8(1)
+ cmd_id(0x0302, 2) + payload(30) + CRC16(2)
```

多字节整数采用小端序。`data_length` 固定为 30；`sequence` 为模 256 递增的单字节帧序号。

### 4.2 30 字节载荷定义

| 偏移 | 长度 | 字段 | 类型 | 内容 |
|---:|---:|---|---|---|
| 0 | 1 | `diagnostic_flags` | `uint8` | 系统状态、超时和警告 |
| 1 | 1 | `node_valid_flags` | `uint8` | A1–A6 与 Handle 有效位 |
| 2 | 1 | `main_buttons` | `uint8` | 主控 KEY1–KEY4 单击、双击事件 |
| 3 | 1 | `handle_buttons` | `uint8` | S1–S4 状态 |
| 4–9 | 6 | `encoder_status[6]` | `uint8[6]` | 六个编码器的采样状态 |
| 10–21 | 12 | `encoder_value[6]` | `int16[6]` | 六个校准后的关节计数 |
| 22–27 | 6 | `joystick_x/y`, `trigger` | `uint16[3]` | 手柄模拟量，范围 0–4095 |
| 28–29 | 2 | `reserved` | `uint16` | 当前为 0 |

### 4.3 状态与有效位

`diagnostic_flags` 的 bit0–1 表示 `INIT`、`ACTIVE`、`DEGRADED`、`DISCONNECTED`；bit2 表示链路超时；bit3–6 依次表示 CRC、格式、磁场和节点数量警告。`node_valid_flags` 的 bit0–5 对应 A1–A6，bit6 对应 Handle。采样中断时数值字段保留最近一次有效值，有效位与诊断字段反映当前状态。

### 4.4 关节计数

每轴校准后的范围为 `-2048…2047`，一圈为 4096 计数。角度为 `encoder_value × 360 / 4096` 度。校准零位的正对侧是 `2047/-2048` 环形折返点。`encoder_status` 的 bit0 表示 I2C 通信、bit1 表示检测到磁铁、bit2/3 表示磁场过弱/过强、bit4 表示数据过期。正常且检测到磁铁时状态值为 `0x03`。

完整字段、CRC 算法和示例帧见[串口协议](SERIAL_PROTOCOL_ZHCN.md)。两版 CCtrl 均使用命令号 `0x0302`，CCtrl-V2 的接收格式由本节的 30 字节载荷定义。

## 5. 输出语义

### 5.1 六轴与腕部

A1–A3 为主体关节，A4–A6 为腕部关节。OLED `Options → Wrist` 的 `XZY` 模式直接输出校准后的 A4–A6；`ZXZ` 模式将同一腕部姿态转换为另一组欧拉角。转换约定为 `Rx(-A4)·Rz(A5)·Ry(-A6) = Rz(α)·Rx(β)·Rz(γ)`。ZXZ 在 β 接近 0° 或 180° 时使用连续分支跟踪；腕部表示的选择保存在 NVS 中。

### 5.2 按键与模拟量

`main_buttons` 低四位是 KEY1–KEY4 的单击事件，高四位是同一组物理键的双击事件。固件使用 20 ms 去抖、300 ms 双击窗口、160 ms 事件脉冲和 200 ms 同键不应期。`handle_buttons` 的 bit0–2 对应 S1–S3；bit3 为扳机产生的 S4，行程达到 80% 时置位，降到 50% 以下时清除。

摇杆 X/Y 与扳机范围为 0–4095，摇杆中心为 2048。主控对摇杆原始 ADC 值进行分段线性映射，Y 轴在映射后反向。校准常数见[Handle 摇杆校准](JOYSTICK_CALIBRATION_ZHCN.md)。

### 5.3 上电休息位姿

`Options → RestGuard` 保存下次上电的保护开关。保护启用时，设备进入已保存的六轴休息区域并稳定 500 ms 之前，RS232 输出保存的标准休息位姿，系统状态为 `DEGRADED`。A1、A5、A6 的进入/退出阈值为 ±30°/±35°；A2–A4 为 ±2°/±3°。位置条件与连续 500 ms 时间条件共同决定进入和退出。USB 页面保存当前六轴健康、新鲜的原始读数作为休息位姿。

## 6. 设备侧配置与校准

OLED `Calibration → Encoder_calibration` 包含 `Zero All 6`、A1–A6 的 `Reverse`、`Save` 与 `Reload`。`Zero All 6` 采集六路 Encoder 当前原始值，将当前位置设为下表的校准角。六路节点存在、I2C 正常且检测到磁铁时，固件将整组校准数据写入 NVS。

| 轴 | `Zero All 6` 后当前位置 |
|---|---:|
| A1 | 0° |
| A2 | +20°，约 228 计数 |
| A3 | +60°，约 683 计数 |
| A4–A6 | 0° |

校准配置包含六路 offset 与 direction，以带版本和 CRC16 的完整 NVS Blob 保存。USB 调试页面显示原始计数、偏移、方向和补偿角度，并提供 0°、±90°、180° 与自定义单轴目标；页面通过带修订号与 CRC 的事务保存整组六轴配置。计算方法见[六路 Encoder 校准](CALIBRATION_ZHCN.md)。

## 7. 上位机工具

- [RS232 通道监视器](../tools/RS232_CHANNEL_MONITOR_ZHCN.md)：`python tools/rs232_channel_monitor.py`。显示协议字段、状态与曲线，并导出当前时间窗口的原始值 CSV。
- [USB Web Serial 调试器](../tools/usb_robot_debug/README.md)：`python tools/usb_robot_debug/server.py`。本地页面位于 `http://127.0.0.1:8768`，显示原始六轴、XZY/ZXZ、诊断、校准与休息位姿。
- [协议参考解析](../tools/protocol_v2.py)：Python 实现的 RS232 帧解析与 CRC 校验。

工具目录与功能见[调试工具](CCtrl-v2_Debug_Tools_ZHCN.md)。

## 8. 构建与烧录

[`platformio.ini`](../platformio.ini) 定义三个固件环境：

| 环境 | 硬件 | 编程协议 | 构建命令 |
|---|---|---|---|
| `master_esp32s3` | ESP32-S3 主板 | esptool | `pio run -e master_esp32s3` |
| `encoder_node_atmega328p` | 8 MHz ATmega328P 编码器节点 | USBasp | `pio run -e encoder_node_atmega328p` |
| `encoder_node_ch32v006` | CH32V006 节点 | WCH-Link | `pio run -e encoder_node_ch32v006` |

PlatformIO 的上传目标为 `pio run -e <环境名> -t upload`。固件文件、依赖和运行职责见[嵌入式固件](CCtrl-v2_Embedded_Firmware_ZHCN.md)。

## 9. 项目资料与验证

| 资料 | 内容 |
|---|---|
| [硬件工程资料](CCtrl-v2_Hardware_Engineering_ZHCN.md) | 主板、手柄模块 v2、带滑环的编码器节点板和滑环电刷的 JLCEDA Pro 工程 |
| [机械模型](CCtrl-v2_Mechanical_Models_ZHCN.md) | 完整装配 STEP、局部改进替换件 STEP 和透明封面图 |
| [节点协议](PROTOCOL_V2.md) | 枚举、轮询、节点记录、状态与 LED |
| [对外串口协议](SERIAL_PROTOCOL_ZHCN.md) | 39 字节帧、30 字节载荷与字段解释 |

项目源码的三个 PlatformIO 环境已完成构建。协议解析测试 12 项、休息位姿与腕部转换的 C++ 测试，以及 USB 帧解析自检均已通过。

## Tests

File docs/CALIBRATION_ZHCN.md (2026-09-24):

# 六路 Encoder 校准

校准数据以一个带版本与 CRC16 的 NVS Blob 保存，其中包含六路 offset 和六路
direction。任何无效 Blob 都会整体拒绝，不会进行部分载入。

OLED 的 `Calibration -> Encoder_calibration` 提供：

- `Zero All 6`：仅当六路 Encoder 均存在、I2C 正常且检测到磁铁时执行。磁场弱、
  磁场强和 stale 状态不阻止置零。操作一次采集六路 raw，并原子写入 NVS；任一路
  不满足基本条件则原有校准保持不变。
- `A1 Reverse` 到 `A6 Reverse`：切换对应方向。
- `Save`：保存方向和 offset。
- `Reload`：从 NVS 重新载入完整 Blob。

计算先在模 4096 下完成：`delta = direction * (raw - offset)`，再将结果转换为
有符号 `int16`。置零位置输出 0，范围为 -2048–2047；经过零位时连续穿过正负数，
环形折返点移动到零位正对面的 -2048/2047 边界。

`Zero All 6` 使用以下目标值：

| 轴 | 当前姿态校准后的值 |
|---|---:|
| A1 | 0° |
| A2 | +20° |
| A3 | +60° |
| A4 | 0° |
| A5 | 0° |
| A6 | 0° |

目标角度会换算为最接近的 4096 计数，并考虑该轴当前的方向设置。A2/A3 即使设为
反向，执行 `Zero All 6` 后仍分别得到正的 +20°/+60°。

Web Serial USB调试器也可编辑任意单轴目标、offset和方向。网页修改仅作为候选，
点击保存后才将完整六轴配置以一个带revision与CRC的事务写入ESP32；写入失败时
继续使用原配置。`+180°`和`-180°`合并为同一个 `180°` 语义。协议和休息位姿说明
见 [USB_DEBUG_ZHCN.md](USB_DEBUG_ZHCN.md)。

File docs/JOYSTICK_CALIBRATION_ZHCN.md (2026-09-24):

# Handle 摇杆校准

以下常数取自 900 个连续 30 Hz 帧，覆盖约 29.97 秒的中心静止和两个轴重复极限运动。

| 轴 | 原始最小值 | 中心 | 原始最大值 | 中心死区 |
|---|---:|---:|---:|---:|
| X | 805 | 2010 | 3226 | ±50 |
| Y | 857 | 1985 | 3150 | ±50 |

ESP32 分别对中心两侧做线性映射：原始最小值及以下输出 0，中心死区输出 2048，
原始最大值及以上输出 4095。上下半程使用独立斜率，以补偿机械中心和两侧行程的
轻微不对称。Handle 节点仍在 Daisy-Chain 中发送原始 ADC 值，校准只发生在
ESP32 主机端。

Y 轴在完成上述标定后反向输出：原始低端对应 4095，原始高端对应 0，中心死区
仍保持 2048。X 轴方向不变。

更换摇杆模块、供电接线、ADC 配置或机械限位后，应重新采样标定。

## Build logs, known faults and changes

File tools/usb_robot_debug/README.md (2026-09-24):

# CCtrl-v2 Web Serial 调试器

ESP32-S3 主机的本地 USB 校准与双姿态监视页面。每次上电 USB 调试均关闭：先在
主菜单进入 `USB Debug`，选择 `Start Debug`，再连接数据线。启动后持续
开启，需要关闭时重启设备；一般业务始终只通过 RS232 输出。

```powershell
python tools\usb_robot_debug\server.py
```

然后使用支持 Web Serial 的 Chrome 或 Edge 打开 <http://127.0.0.1:8768>。

ESP32 在 30 Hz 输出节拍中同时计算 XZY 和 ZXZ，USB 调试约 15 Hz 发送最近快照；
页面直接展示设备生成的两组结果。RS232 按选定的 Wrist 格式输出。

诊断区以8位显示主机快捷键事件：低4位为KEY1–KEY4单击，高4位为对应双击
KEY5–KEY8。

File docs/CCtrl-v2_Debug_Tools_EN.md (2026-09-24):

# CCtrl-V2 Debug Tools

[ZHCN](CCtrl-v2_Debug_Tools_ZHCN.md) | [EN](CCtrl-v2_Debug_Tools_EN.md)

This page lists the RS232 monitor, USB debugging page, and protocol reference implementation.

## Main files and directories

| Entry | Function |
|---|---|
| [rs232_channel_monitor.py](../tools/rs232_channel_monitor.py) | Parses RS232 `0x0302` frames, plots channels, exports CSV |
| [start_rs232_channel_monitor.bat](../tools/start_rs232_channel_monitor.bat) | Windows monitor launcher |
| [usb_robot_debug](../tools/usb_robot_debug) | Local Web Serial page, frame parsing, calibration, rest-pose controls |
| [protocol_v2.py](../tools/protocol_v2.py) | Python frame parser and CRC reference implementation |

## Launch commands

| Tool | Command | Interface |
|---|---|---|
| RS232 channel monitor | `python tools/rs232_channel_monitor.py` | RS232 adapter, 115200 8N1 |
| USB debug page | `python tools/usb_robot_debug/server.py` | `http://127.0.0.1:8768`; browser Web Serial at 2000000 baud |

The RS232 monitor reads 39-byte business frames and displays joints, validity, status, buttons, joystick, and trigger. Its plot window and CSV preserve raw protocol values. With `USB Debug → Start Debug` enabled on the device, the USB page shows raw-axis, XZY, ZXZ, and diagnostic snapshots at about 15 Hz and sends calibration and rest-pose configuration commands.

## Related documents

- [User manual](CCtrl-v2_User_Manual_EN.md)
- [Monitor guide](../tools/RS232_CHANNEL_MONITOR_ZHCN.md)
- [USB page guide](../tools/usb_robot_debug/README.md)
- [USB debug protocol](USB_DEBUG_ZHCN.md)

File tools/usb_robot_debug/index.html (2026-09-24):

CCTRL / USB DEBUG

# USB 校准与姿态调试器

ESP32 同步输出控制器 XZY 与机械臂 ZXZ；网页仅展示设备计算结果

演示数据连接设备

未连接

RATE 0.0 HzSEQ --VALID 00LAT 0 μs

ERROR 00休息区域：否上电保护：ON

ENCODER CALIBRATION

## 六关节校准

重新读取保存到 ESP32

关节 | 状态 | 原始值 | 当前补偿值 | 方向 | 补偿后角度 | 校准当前位置到

所有修改先在页面形成候选配置，点击保存后才以单个事务写入 ESP32。180°为同一语义，不区分 +180°与 −180°。

A

## 控制器

XZYESP32 结果

B

## 机械臂

ZXZESP32 结果

DIAGNOSTICS

## 状态与输入

控制器状态INIT

警告00

主机按键 K8…K100000000

手柄按键0000

摇杆 X / Y0 / 0

扳机0

丢失轮询0

USB未连接

启用上电休息位姿保护将当前位姿设为休息位姿

Web Serial · 2,000,000 baud · Protocol 1 · 15 Hz telemetry · 4096 counts/rev

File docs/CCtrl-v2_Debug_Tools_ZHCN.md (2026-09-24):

# CCtrl-V2 调试工具

[ZHCN](CCtrl-v2_Debug_Tools_ZHCN.md) | [EN](CCtrl-v2_Debug_Tools_EN.md)

本页汇总仓库中的 RS232 监视器、USB 调试页面和协议参考实现。

## 主要文件与目录

| 入口 | 功能 |
|---|---|
| [rs232_channel_monitor.py](../tools/rs232_channel_monitor.py) | 解析 RS232 `0x0302` 帧，显示字段和曲线，导出 CSV |
| [start_rs232_channel_monitor.bat](../tools/start_rs232_channel_monitor.bat) | Windows 监视器启动入口 |
| [usb_robot_debug](../tools/usb_robot_debug) | Web Serial 本地页面、帧解析、校准及休息位姿操作 |
| [protocol_v2.py](../tools/protocol_v2.py) | Python 帧解析与 CRC 参考实现 |

## 启动方式

| 工具 | 命令 | 接口 |
|---|---|---|
| RS232 通道监视器 | `python tools/rs232_channel_monitor.py` | 115200 8N1 的 RS232 转接串口 |
| USB 调试页面 | `python tools/usb_robot_debug/server.py` | `http://127.0.0.1:8768`；浏览器 Web Serial，2000000 baud |

RS232 通道监视器以 39 字节业务帧为输入，显示六轴、有效位、状态、按键、摇杆和扳机；曲线窗口与 CSV 使用协议原始数值。USB 页面在设备的 `USB Debug → Start Debug` 开启后连接，显示约 15 Hz 的原始六轴、XZY、ZXZ 与诊断快照，并发送校准、休息位姿配置命令。

## 相关文档

- [用户手册](CCtrl-v2_User_Manual_ZHCN.md)
- [监视器说明](../tools/RS232_CHANNEL_MONITOR_ZHCN.md)
- [USB 页面说明](../tools/usb_robot_debug/README.md)
- [USB 调试协议](USB_DEBUG_ZHCN.md)

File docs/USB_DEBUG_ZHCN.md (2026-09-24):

# CCtrl-v2 USB 串口调试协议

## 1. 启停和业务隔离

- ESP32-S3 每次上电时 USB CDC 默认关闭。
- 从主菜单进入 `USB Debug` 并选择 `Start Debug`，随后设备枚举 USB
  调试串口。调试串口持续开启至设备重启。
- Daisy-Chain 采样仍约45 Hz；一般业务始终只从 RS232 以约30 Hz输出，帧不变。
- XZY和ZXZ在既有主机输出时点同时生成；USB以约15 Hz发送最近快照，不再次推进
  ZXZ连续跟随状态。网页只展示两份设备结果，不做轴序换算。

本地页面位于 `tools/usb_robot_debug`：

```powershell
python tools\usb_robot_debug\server.py
```

## 2. 串口帧

USB CDC 名称为 `CCtrl USB Debug`，网页以2,000,000 baud打开。所有多字节字段均为
小端。每帧格式如下：

```text
43 44 | version:u8 | type:u8 | sequence:u8 | payload_len:u8 |
payload[0..32] | crc16:u16
```

CRC16覆盖帧头和payload，不含末尾CRC本身。版本当前为1。

| type | payload |
|---:|---|
| `01` | `valid:u8, raw[6]:u16` |
| `02` | `valid:u8, xzy[6]:i16` |
| `03` | `valid:u8, zxz[6]:i16` |
| `04` | 状态、错误、警告、按键、休息标志、摇杆、扳机、延迟、丢失轮询 |
| `05` | `revision:u16, offset[6]:u16, direction_mask:u8` |
| `06` | `revision:u16, rest_raw[6]:u16, flags:u8` |
| `07` | 命令结果 |
| `80` | 网页发往ESP32的命令 |

XZY/ZXZ 均为一圈 4096 计数的有符号值；USB 页面展示设备发送的两组结果，
不自行重新计算 ZXZ。轴序和方向约定见 [串口协议](SERIAL_PROTOCOL_ZHCN.md)。

## 3. 命令

- `01`：读取校准配置和休息位姿。
- `10 revision:u16 offset[6]:u16 direction_mask:u8`：原子应用并保存六轴校准。
- `20`：将当前六路fresh、健康的原始值保存为休息位姿。
- `21 00/01`：关闭或启用下次上电的休息位姿保护。

## 4. 休息位姿保护

- A1、A5、A6进入阈值为±30°，退出阈值为±35°；A2–A4进入±2°，退出±3°。
- 六个关节均参与休息位姿判定和休息位姿记录。
- 进入和退出均须同时满足位置迟滞条件和连续500 ms时间条件。
- 保护启用时，上电持续发送保存的标准休息位姿，直到进入休息区域500 ms。
- 保护激活属于 `CCTRL_ERROR_REST_REQUIRED`，点亮ERR灯；不增加鸣叫、音乐、
  专用页面或三秒提示。
- 休息区域内屏蔽腕部接近限位提醒。关闭保护不关闭该区域判定和提醒屏蔽。

## 5. 校准页面

每轴显示原始计数/角度、offset、方向和补偿后角度。支持任意目标以及
`0°/-90°/90°/180°`；`+180°`和`-180°`合并为同一个语义。网页只形成候选，
点击保存后才上传完整六轴事务。

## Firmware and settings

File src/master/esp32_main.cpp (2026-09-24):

#include "../shared/crc.h"
#include "../shared/protocol_v2.h"
#include "usb_debug_service.h"
#include "master_business.h"
#include "joystick_model.h"
#include "rest_pose.h"
#include "trigger_model.h"
#include "wrist_orientation.h"

#include <Arduino.h>
#include <Preferences.h>
#include <string.h>

namespace {
constexpr uint8_t PIN_CHAIN_TX = 17;
constexpr uint8_t PIN_CHAIN_RX = 18;
constexpr uint8_t PIN_RS232_TX = 15;
constexpr uint8_t PIN_RS232_RX = 16;
constexpr uint8_t KEY_PINS[4] = {35, 36, 37, 38};
constexpr uint32_t BUS_BAUD = 250000;
constexpr uint32_t RS232_BAUD = 115200;
constexpr uint32_t POLL_US = 22222;
constexpr uint32_t HOST_OUTPUT_US = 33334; // <= RoboMaster 30 Hz limit
constexpr uint32_t RESPONSE_TIMEOUT_US = 18000;
constexpr uint32_t LINK_TIMEOUT_MS = 500;
constexpr uint32_t WARNING_HOLD_MS = 2000;
constexpr uint32_t KEY_DOUBLE_CLICK_MS = 300;
constexpr uint32_t KEY_REFRACTORY_MS = 200;
constexpr uint32_t KEY_DEBOUNCE_MS = 20;
constexpr uint32_t KEY_OUTPUT_PULSE_MS = 160;
constexpr uint32_t KEY_AUDIO_PULSE_MS = 80;
constexpr uint32_t ENUM_PERIOD_MS = 500;
constexpr uint32_t POPUP_MIN_MS = 1000;
constexpr uint32_t CAL_MAGIC = 0x364C4143u; // CAL6
constexpr uint8_t CAL_VERSION = 1;
constexpr uint32_t REST_MAGIC = 0x31545352u; // RST1
constexpr uint8_t REST_VERSION = 1;
constexpr uint16_t TRIGGER_S4_ON = 3276;  // 80% of 4095
constexpr uint16_t TRIGGER_S4_OFF = 2048; // release below 50%

struct __attribute__((packed)) CalibrationBlob {
  uint32_t magic;
  uint8_t version;
  uint8_t reserved;
  uint16_t offset[6];
  int8_t direction[6];
  uint16_t crc;
};
static_assert(sizeof(CalibrationBlob) == 26, "calibration blob size");

struct __attribute__((packed)) RestPoseBlob {
  uint32_t magic;
  uint8_t version;
  uint8_t reserved;
  uint16_t raw[6];
  uint16_t revision;
  uint16_t crc;
};
static_assert(sizeof(RestPoseBlob) == 22, "rest pose blob size");

Preferences prefs;
HardwareSerial chainSerial(1);
HardwareSerial rs232Serial(2);
CctrlBusParser busParser{};

uint8_t busSequence;
uint8_t pollSequence;
uint8_t hostSequence;
bool enumerated;
bool awaitingPoll;
uint8_t expectedSequence;
uint8_t encoderSlotByNode[16];
uint8_t nodeTypeByNode[16];
uint8_t totalNodes;
uint8_t observedEncoders;
uint8_t observedHandles;
uint8_t encoderValidMask;
bool handleValid;
uint8_t errorFlags;
uint8_t warningFlags;
uint32_t warningUntilMs[4];
uint8_t systemStatus = CCTRL_SYSTEM_INIT;
uint8_t encoderStatus[6] = {0};
uint16_t encoderRaw[6] = {0};
int16_t encoderCalibrated[6] = {0};
int16_t encoderOutput[6] = {0};
int16_t encoderXzy[6] = {0};
int16_t encoderZxz[6] = {0};
uint32_t encoderSeenMs[6] = {0};
uint16_t handleX, handleY;
int16_t handleMagX, handleMagY, handleMagZ;
uint16_t handleTrigger;
uint8_t handleStatus;
uint8_t handleButtons;
bool triggerS4Active;
uint8_t mainButtonsRaw;
uint8_t mainButtonsHost;
uint8_t mainButtonsAudio;
uint8_t keyDoubleClickFlags;
struct KeyClickState {
  bool sampledDown;
  bool debouncedDown;
  bool wasDown;
  bool firstReleased;
  uint8_t phase;      // 0=ready, 1=wait second press, 2=refractory
  uint8_t outputKind; // 0=none, 1=single, 2=double
  uint32_t sampledChangedMs;
  uint32_t deadlineMs;
  uint32_t outputUntilMs;
  uint32_t audioUntilMs;
  uint32_t doubleToneUntilMs;
};
KeyClickState keyClickState[4];
bool bootSound = true;
bool wristZxzEnabled;
bool restProtectionEnabled = true;
bool startupRestProtectionActive = true;
bool tileMenuActive;
uint8_t tileCommand;
uint32_t linkInitCount;
uint32_t lastEnumMs;
uint32_t lastBusFrameMs;
uint32_t pollSentUs;
uint32_t nextPollUs;
uint32_t nextOutputUs;
uint32_t totalPolls;
uint32_t lostPolls;
uint32_t crcFailures;
uint32_t formatFailures;
uint32_t nodeCountWarnings;
uint32_t magnetWarnings;
uint8_t lastPollSequence;
bool haveLastPollSequence;
uint32_t pollStartedUs[256] = {0};
uint8_t pollTimestampValid[256] = {0};
uint32_t chainLatencyUs;
uint32_t chainLatencyAvgUs;
uint32_t chainLatencyMaxUs;
CalibrationBlob calibration{};
RestPoseBlob restPose{};
RestPose::State restRegionState{};
uint16_t calibrationRevision;
WristOrientation::State wristOrientationState{};
UiPopupState popup{};
uint32_t popupUntilMs;

constexpr uint16_t degreesToCounts(uint16_t degree);
bool encoderCalibrationHealthy(uint8_t status);

void setPopup(const char *text) {
  popup.active = 1;
  strncpy(popup.text, text, sizeof(popup.text) - 1);
  popup.text[sizeof(popup.text) - 1] = 0;
  popupUntilMs = millis() + POPUP_MIN_MS;
}

void setWarning(uint8_t warning) {
  warningFlags |= warning;
  for (uint8_t i = 0; i < 4; ++i)
    if (warning == (uint8_t)(1u << i)) warningUntilMs[i] = millis() + WARNING_HOLD_MS;
}

void refreshWarnings() {
  for (uint8_t i = 0; i < 4; ++i)
    if ((warningFlags & (1u << i)) &&
        (int32_t)(millis() - warningUntilMs[i]) >= 0)
      warningFlags &= (uint8_t)~(1u << i);
}

uint16_t calibrationCrc(const CalibrationBlob &blob) {
  return rm_crc16(reinterpret_cast<const uint8_t *>(&blob),
                  offsetof(CalibrationBlob, crc));
}

uint16_t restPoseCrc(const RestPoseBlob &blob) {
  return rm_crc16(reinterpret_cast<const uint8_t *>(&blob),
                  offsetof(RestPoseBlob, crc));
}

void defaultsCalibration() {
  memset(&calibration, 0, sizeof(calibration));
  calibration.magic = CAL_MAGIC;
  calibration.version = CAL_VERSION;
  for (uint8_t i = 0; i < 6; ++i) calibration.direction[i] = 1;
  calibration.crc = calibrationCrc(calibration);
}

bool loadCalibration() {
  CalibrationBlob candidate{};
  if (prefs.getBytesLength("enc_cal") != sizeof(candidate) ||
      prefs.getBytes("enc_cal", &candidate, sizeof(candidate)) != sizeof(candidate) ||
      candidate.magic != CAL_MAGIC || candidate.version != CAL_VERSION ||
      candidate.crc != calibrationCrc(candidate)) {
    return false;
  }
  for (uint8_t i = 0; i < 6; ++i)
    if (candidate.direction[i] != 1 && candidate.direction[i] != -1) return false;
  calibration = candidate;
  return true;
}

bool storeCalibration() {
  calibration.crc = calibrationCrc(calibration);
  return prefs.putBytes("enc_cal", &calibration, sizeof(calibration)) ==
         sizeof(calibration);
}

uint16_t rawForTarget(uint16_t offset, int8_t direction,
                      uint16_t targetCounts) {
  return direction > 0 ? (uint16_t)((offset + targetCounts) & 0x0FFFu)
                       : (uint16_t)((offset - targetCounts) & 0x0FFFu);
}

void defaultsRestPose() {
  memset(&restPose, 0, sizeof(restPose));
  restPose.magic = REST_MAGIC;
  restPose.version = REST_VERSION;
  const uint16_t target[6] = {0, degreesToCounts(20), degreesToCounts(60),
                              0, 0, 0};
  for (uint8_t i = 0; i < 6; ++i)
    restPose.raw[i] =
        rawForTarget(calibration.offset[i], calibration.direction[i], target[i]);
  restPose.revision = 1;
  restPose.crc = restPoseCrc(restPose);
}

bool loadRestPose() {
  RestPoseBlob candidate{};
  if (prefs.getBytesLength("rest_pose") != sizeof(candidate) ||
      prefs.getBytes("rest_pose", &candidate, sizeof(candidate)) !=
          sizeof(candidate) ||
      candidate.magic != REST_MAGIC || candidate.version != REST_VERSION ||
      candidate.crc != restPoseCrc(candidate))
    return false;
  restPose = candidate;
  return true;
}

bool storeRestPose(const RestPoseBlob &candidate) {
  return prefs.putBytes("rest_pose", &candidate, sizeof(candidate)) ==
         sizeof(candidate);
}

int16_t calibrateRaw(uint16_t raw, uint16_t offset, int8_t direction) {
  uint16_t delta = (raw - offset) & 0x0FFFu;
  if (direction < 0) delta = (uint16_t)((4096u - delta) & 0x0FFFu);
  return delta >= 2048u ? (int16_t)((int32_t)delta - 4096) : (int16_t)delta;
}

void updateCalibrated() {
  for (uint8_t i = 0; i < 6; ++i) {
    encoderCalibrated[i] = calibrateRaw(
        encoderRaw[i], calibration.offset[i], calibration.direction[i]);
  }
  if (!wristZxzEnabled)
    memcpy(encoderOutput, encoderCalibrated, sizeof(encoderOutput));
}

void updateEncoderOutputForHost() {
  int16_t source[6];
  if (startupRestProtectionActive) {
    for (uint8_t i = 0; i < 6; ++i)
      source[i] = calibrateRaw(restPose.raw[i], calibration.offset[i],
                               calibration.direction[i]);
  } else {
    memcpy(source, encoderCalibrated, sizeof(source));
  }
  memcpy(encoderXzy, source, sizeof(encoderXzy));
  encoderXzy[3] = (int16_t)-source[3];
  encoderXzy[5] = (int16_t)-source[5];
  memcpy(encoderZxz, source, sizeof(encoderZxz));
  if (encoderSeenMs[3] != 0 && encoderSeenMs[4] != 0 &&
      encoderSeenMs[5] != 0)
    WristOrientation::xzyToZxz(source + 3, encoderZxz + 3,
                               wristOrientationState);
  memcpy(encoderOutput, wristZxzEnabled ? encoderZxz : source,
         sizeof(encoderOutput));
}

bool restSensorsHealthy() {
  if ((encoderValidMask & 0x1Fu) != 0x1Fu) return false;
  for (uint8_t i = 0; i < 5; ++i)
    if (!encoderCalibrationHealthy(encoderStatus[i])) return false;
  return true;
}

void updateRestProtection(uint32_t nowMs) {
  RestPose::update(restRegionState, encoderRaw, restPose.raw,
                   restSensorsHealthy(), nowMs);
  if (startupRestProtectionActive && restRegionState.in_region)
    startupRestProtectionActive = false;
  if (startupRestProtectionActive) {
    errorFlags |= CCTRL_ERROR_REST_REQUIRED;
    if (systemStatus != CCTRL_SYSTEM_DISCONNECTED)
      systemStatus = CCTRL_SYSTEM_DEGRADED;
  }
}

bool encoderCalibrationHealthy(uint8_t status) {
  const uint8_t required = CCTRL_ENC_I2C_OK | CCTRL_ENC_MAGNET_DETECTED;
  return (status & required) == required;
}

constexpr uint16_t degreesToCounts(uint16_t degree) {
  return (uint16_t)((((uint32_t)(degree % 360u) * 4096u) + 180u) / 360u);
}
static_assert(degreesToCounts(20) == 228, "A2 target count");
static_assert(degreesToCounts(60) == 683, "A3 target count");

uint16_t offsetForTarget(uint16_t raw, int8_t direction,
                         uint16_t targetCounts) {
  return direction > 0 ? (uint16_t)((raw - targetCounts) & 0x0FFFu)
                       : (uint16_t)((raw + targetCounts) & 0x0FFFu);
}

void resetTopology() {
  memset(encoderSlotByNode, 0xFF, sizeof(encoderSlotByNode));
  memset(nodeTypeByNode, 0, sizeof(nodeTypeByNode));
  totalNodes = observedEncoders = observedHandles = 0;
  encoderValidMask = 0;
  handleValid = false;
  enumerated = false;
}

void sendBusFrame(uint8_t messageType) {
  uint8_t frame[CCTRL_BUS_MAX_FRAME];
  cctrl_bus_init(frame, messageType,
                 messageType == CCTRL_MSG_POLL ? pollSequence++ : busSequence++);
  cctrl_bus_finalize(frame);
  if (messageType == CCTRL_MSG_POLL) {
    const uint8_t pollSequence = frame[4];
    pollStartedUs[pollSequence] = micros();
    pollTimestampValid[pollSequence] = 1;
    awaitingPoll = true;
    expectedSequence = pollSequence;
    pollSentUs = micros();
    ++totalPolls;
  }
  chainSerial.write(frame, cctrl_bus_size(frame));
}

void updateChainLatency(uint8_t pollSequence) {
  if (!pollTimestampValid[pollSequence]) return;
  pollTimestampValid[pollSequence] = 0;
  chainLatencyUs = micros() - pollStartedUs[pollSequence];
  if (chainLatencyAvgUs == 0)
    chainLatencyAvgUs = chainLatencyUs;
  else
    chainLatencyAvgUs = (chainLatencyAvgUs * 7u + chainLatencyUs) / 8u;
  if (chainLatencyUs > chainLatencyMaxUs) chainLatencyMaxUs = chainLatencyUs;
}
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
void loop() {
  serviceBusRx();
  readMainButtons();
  const uint32_t nowUs = micros();
  const uint32_t nowMs = millis();
  if ((!enumerated || nowMs - lastBusFrameMs > LINK_TIMEOUT_MS) &&
      nowMs - lastEnumMs >= ENUM_PERIOD_MS) {
    lastEnumMs = nowMs;
    resetTopology();
    sendBusFrame(CCTRL_MSG_ENUM_RESET);
  }
  if (enumerated && !awaitingPoll && (int32_t)(nowUs - nextPollUs) >= 0) {
    nextPollUs += POLL_US;
    sendBusFrame(CCTRL_MSG_POLL);
  }
  if (awaitingPoll && nowUs - pollSentUs > RESPONSE_TIMEOUT_US) {
    awaitingPoll = false;
  }
  updateSystemState();
  updateRestProtection(nowMs);
  if ((int32_t)(nowUs - nextOutputUs) >= 0) {
    nextOutputUs += HOST_OUTPUT_US;
    if ((int32_t)(nowUs - nextOutputUs) >= 0)
      nextOutputUs = nowUs + HOST_OUTPUT_US;
    emitHostFrame();
  }
  UsbDebugService::loop(nowMs);
}

bool getMonitorSnapshot(UiMonitorSnapshot &out) {
  out = UiMonitorSnapshot{};
  out.totalNodes = totalNodes;
  out.observedEnc = observedEncoders;
  out.observedHnd = observedHandles;
  out.errFlags = errorFlags;
  out.warningFlags = warningFlags;
  out.controllerStatus = systemStatus;
  out.nodeValidFlags = encoderValidMask | (handleValid ? 0x40 : 0);
  memcpy(out.encStatus, encoderStatus, sizeof(encoderStatus));
  memcpy(out.enc, encoderOutput, sizeof(encoderOutput));
  memcpy(out.encCalibrated, encoderCalibrated, sizeof(encoderCalibrated));
  memcpy(out.encXzy, encoderXzy, sizeof(encoderXzy));
  memcpy(out.encZxz, encoderZxz, sizeof(encoderZxz));
  memcpy(out.encRaw, encoderRaw, sizeof(encoderRaw));
  memcpy(out.encOffset, calibration.offset, sizeof(calibration.offset));
  memcpy(out.encDirection, calibration.direction, sizeof(calibration.direction));
  out.joystickX = handleX;
  out.joystickY = handleY;
  out.trigger = handleTrigger;
  out.handleButtons = handleButtons;
  out.keyFlags = mainButtonsHost;
  out.keyAudioFlags = mainButtonsAudio;
  out.keyDoubleClickFlags = keyDoubleClickFlags;
  out.wristLimitActive =
      wristZxzEnabled && wristOrientationState.soft_limited &&
              !restRegionState.in_region
          ? 1
          : 0;
  out.disconnectMode = systemStatus == CCTRL_SYSTEM_DISCONNECTED;
  out.restInRegion = restRegionState.in_region ? 1 : 0;
  out.restProtectionEnabled = restProtectionEnabled ? 1 : 0;
  out.restProtectionActive = startupRestProtectionActive ? 1 : 0;
  out.usbDebugEnabled = UsbDebugService::enabled() ? 1 : 0;
  out.usbConnected = UsbDebugService::connected() ? 1 : 0;
  out.lossRate10s = totalPolls ? (100.0f * lostPolls / totalPolls) : 0.0f;
  out.chainLatencyUs = chainLatencyUs;
  out.chainLatencyAvgUs = chainLatencyAvgUs;
  out.chainLatencyMaxUs = chainLatencyMaxUs;
  out.lostPolls = lostPolls;
  out.crcFailures = crcFailures;
  out.formatFailures = formatFailures;
  out.nodeCountWarnings = nodeCountWarnings;
  out.magnetWarnings = magnetWarnings;
  out.valid = 1;
  return true;
}

bool getUiPopupState(UiPopupState &out) {
  if (popup.active && (int32_t)(millis() - popupUntilMs) >= 0)
    popup.active = 0;
  out = popup;
  return true;
}
uint8_t getLocalKeyMaskRaw() { return mainButtonsRaw; }
bool setTileMenuActive(bool active) { tileMenuActive = active; return true; }
bool getTileMenuActive() { return tileMenuActive; }
bool triggerTileMenuCommand(uint8_t command) { tileCommand = command; return true; }

bool zeroAllEncoders() {
  if (encoderValidMask != 0x3Fu) {
    setPopup("Need 6 encoders");
    return false;
  }
  for (uint8_t i = 0; i < 6; ++i) {
    if (!encoderCalibrationHealthy(encoderStatus[i])) {
      setPopup("Encoder not ready");
      return false;
    }
  }
  CalibrationBlob candidate = calibration;
  memcpy(candidate.offset, encoderRaw, sizeof(candidate.offset));
  candidate.offset[1] = offsetForTarget(
      encoderRaw[1], candidate.direction[1], degreesToCounts(20));
  candidate.offset[2] = offsetForTarget(
      encoderRaw[2], candidate.direction[2], degreesToCounts(60));
  candidate.crc = calibrationCrc(candidate);
  if (prefs.putBytes("enc_cal", &candidate, sizeof(candidate)) != sizeof(candidate)) {
    setPopup("NVS write failed");
    return false;
  }
  calibration = candidate;
  ++calibrationRevision;
  updateCalibrated();
  setPopup("Calibrated all 6");
  return true;
}

bool getEncoderCalibrationState(EncoderCalibrationState &out) {
  memcpy(out.raw, encoderRaw, sizeof(out.raw));
  memcpy(out.offset, calibration.offset, sizeof(out.offset));
  memcpy(out.dir, calibration.direction, sizeof(out.dir));
  memcpy(out.calibrated, encoderCalibrated, sizeof(out.calibrated));
  out.revision = calibrationRevision;
  return true;
}

bool calibrateEncoderAxisToDegree(uint8_t axis, uint16_t degree) {
  if (axis >= 6 || !(encoderValidMask & (1u << axis)) ||
      !encoderCalibrationHealthy(encoderStatus[axis])) return false;
  const uint16_t target = degreesToCounts(degree);
  calibration.offset[axis] = offsetForTarget(
      encoderRaw[axis], calibration.direction[axis], target);
  ++calibrationRevision;
  updateCalibrated();
  return true;
}

bool toggleEncoderDirection(uint8_t axis) {
  if (axis >= 6) return false;
  calibration.direction[axis] = -calibration.direction[axis];
  ++calibrationRevision;
  updateCalibrated();
  return true;
}
bool applyEncoderCalibration(const uint16_t offset[6], const int8_t dir[6],
                             uint16_t expectedRevision) {
  if (!offset || !dir || expectedRevision != calibrationRevision) return false;
  CalibrationBlob candidate = calibration;
  for (uint8_t i = 0; i < 6; ++i) {
    if (offset[i] > 4095u || (dir[i] != 1 && dir[i] != -1)) return false;
    candidate.offset[i] = offset[i];
    candidate.direction[i] = dir[i];
  }
  candidate.crc = calibrationCrc(candidate);
  if (prefs.putBytes("enc_cal", &candidate, sizeof(candidate)) !=
      sizeof(candidate))
    return false;
  calibration = candidate;
  ++calibrationRevision;
  updateCalibrated();
  return true;
}
bool saveEncoderCalibration() {
  const bool ok = storeCalibration();
  setPopup(ok ? "Calibration saved" : "Save failed");
  return ok;
}
bool reloadEncoderCalibration() {
  const bool ok = loadCalibration();
  if (ok) {
    ++calibrationRevision;
    updateCalibrated();
  }
  setPopup(ok ? "Calibration loaded" : "Invalid calibration");
  return ok;
}
bool setBootSoundEnabled(bool enabled) { bootSound = enabled; prefs.putBool("boot_sound", enabled); return true; }
bool getBootSoundEnabled() { return bootSound; }
bool setWristZxzEnabled(bool enabled) {
  wristZxzEnabled = enabled;
  WristOrientation::reset(wristOrientationState);
  updateCalibrated();
  prefs.putBool("wrist_zxz", enabled);
  setPopup(enabled ? "Wrist output: ZXZ" : "Wrist output: XZY");
  return true;
}
bool getWristZxzEnabled() { return wristZxzEnabled; }
bool getRestPoseState(RestPoseState &out) {
  memcpy(out.raw, restPose.raw, sizeof(out.raw));
  out.revision = restPose.revision;
  out.inRegion = restRegionState.in_region ? 1 : 0;
  out.protectionEnabled = restProtectionEnabled ? 1 : 0;
  out.protectionActive = startupRestProtectionActive ? 1 : 0;
  return true;
}
bool setCurrentPoseAsRest() {
  if (encoderValidMask != 0x3Fu) return false;
  for (uint8_t i = 0; i < 6; ++i)
    if (!encoderCalibrationHealthy(encoderStatus[i])) return false;
  RestPoseBlob candidate = restPose;
  memcpy(candidate.raw, encoderRaw, sizeof(candidate.raw));
  ++candidate.revision;
  candidate.crc = restPoseCrc(candidate);
  if (!storeRestPose(candidate)) return false;
  restPose = candidate;
  restRegionState = RestPose::State{};
  return true;
}
bool setRestProtectionEnabled(bool enabled) {
  restProtectionEnabled = enabled;
  if (!enabled) startupRestProtectionActive = false;
  prefs.putBool("rest_guard", enabled);
  return true;
}
bool getRestProtectionEnabled() { return restProtectionEnabled; }
bool startUsbDebug() { return UsbDebugService::requestStart(); }
bool getUsbDebugEnabled() { return UsbDebugService::enabled(); }
bool getUsbConnected() { return UsbDebugService::connected(); }
uint32_t getLinkInitSuccessCount() { return linkInitCount; }

} // namespace MasterBusiness

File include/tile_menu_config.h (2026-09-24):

#pragma once

#include <Arduino.h>

struct TileMenuConfigEntry {
  const char *title;
  const uint8_t *icon;
  uint8_t command;
};

namespace TileMenuConfig {

constexpr uint8_t kMaxItems = 15;
constexpr uint8_t kIconWidth = 30;
constexpr uint8_t kIconHeight = 30;
constexpr size_t kIconBytes = ((kIconWidth + 7U) / 8U) * kIconHeight;
constexpr uint8_t kVisibleIndicatorWidth = 7;
constexpr uint8_t kVisibleIndicatorHeight = 27;
constexpr uint8_t kIconSpacing = 36;
constexpr uint8_t kIndicatorTop = 36;

// TILE icons use the upstream 30x30 1-bit XBM-style layout.
// Each byte packs 8 pixels, so 30x30 needs 4 bytes per row * 30 rows = 120 bytes.
// Leave title empty or command 0 to hide an item without losing its icon data.

static const uint8_t kTileIcon00[kIconBytes] PROGMEM = {
    0xFF,0xFF,0xFF,0x3F,0xFF,0xFF,0xFF,0x3F,0xFF,0xFF,0xFF,0x3F,0xFF,0x01,0xFF,0x3F,
    0x7F,0x00,0xDC,0x3F,0x3F,0x00,0xC8,0x3F,0x1F,0x00,0xC0,0x3F,0x0F,0x7E,0xC0,0x3F,
    0x87,0xFF,0xC1,0x3F,0xC3,0xFF,0xC0,0x3F,0xC3,0x7F,0xC0,0x3F,0xE3,0xFF,0xFF,0x3B,
    0xE1,0xFF,0xFF,0x3B,0xE1,0xFF,0xFF,0x31,0xE1,0xFF,0x7F,0x00,0xE1,0xFF,0xFF,0x31,
    0xE1,0xFF,0xDF,0x3B,0xE3,0xFF,0xDF,0x3B,0xC3,0xFF,0x8F,0x3F,0xC3,0xFF,0x8F,0x3F,
    0x83,0xFF,0x03,0x3E,0x07,0xFE,0x00,0x38,0x0F,0x80,0x03,0x3E,0x1F,0x00,0x8F,0x3F,
    0x7F,0x00,0x8E,0x3F,0xFF,0x00,0xDE,0x3F,0xFF,0xFF,0xDF,0x3F,0xFF,0xFF,0xFF,0x3F,
    0xFF,0xFF,0xFF,0x3F,0xFF,0xFF,0xFF,0x3F,
};

static const uint8_t kTileIcon01[kIconBytes] PROGMEM = {
    0xFF,0xFF,0xFF,0x3F,0xFF,0xFF,0xFF,0x3F,0xFF,0xFF,0xFF,0x3F,0xFF,0xFF,0xFF,0x3F,
    0xFF,0xFF,0xFF,0x3F,0xFF,0xFF,0xFF,0x3F,0xFF,0xFF,0xFF,0x3F,0x07,0x80,0xFF,0x3F,
    0x03,0x00,0xFF,0x3F,0x03,0x00,0xFF,0x3F,0x07,0x80,0xF7,0x3F,0x5F,0xEB,0xF3,0x3F,
    0x5F,0xEB,0xF1,0x3F,0x5F,0xEB,0x00,0x30,0x5F,0x6B,0x00,0x30,0x5F,0x2B,0x00,0x30,
    0x5F,0x2B,0x00,0x30,0x5F,0x6B,0x00,0x30,0x5F,0xEB,0x00,0x30,0x5F,0xEB,0xF1,0x3F,
    0x5F,0xEB,0xF3,0x3F,0x5F,0xEB,0xF7,0x3F,0x5F,0xEB,0xFF,0x3F,0x07,0x80,0xFF,0x3F,
    0x07,0x80,0xFF,0x3F,0x0F,0xC0,0xFF,0x3F,0xFF,0xFF,0xFF,0x3F,0xFF,0xFF,0xFF,0x3F,
    0xFF,0xFF,0xFF,0x3F,0xFF,0xFF,0xFF,0x3F,
};

static const uint8_t kTileIcon02[kIconBytes] PROGMEM = {
    0xFF,0xFF,0xFF,0x3F,0xFF,0xFF,0xFF,0x3F,0xFF,0xFF,0xFF,0x3F,0xFF,0xFF,0xFF,0x3F,
    0xFF,0xFF,0xFF,0x3F,0xFF,0xFF,0xFF,0x3F,0xFF,0xFF,0xFF,0x3F,0xFF,0x7F,0x00,0x38,
    0xFF,0x3F,0x00,0x30,0xFF,0x3F,0x00,0x30,0xFF,0x7B,0x00,0x38,0xFF,0xF3,0xB5,0x3E,
    0xFF,0xE3,0xB5,0x3E,0x03,0xC0,0xB5,0x3E,0x03,0x80,0xB5,0x3E,0x03,0x00,0xB5,0x3E,
    0x03,0x00,0xB5,0x3E,0x03,0x80,0xB5,0x3E,0x03,0xC0,0xB5,0x3E,0xFF,0xE3,0xB5,0x3E,
    0xFF,0xF3,0xB5,0x3E,0xFF,0xFB,0xB5,0x3E,0xFF,0xFF,0xB5,0x3E,0xFF,0x7F,0x00,0x38,
    0xFF,0x7F,0x00,0x38,0xFF,0xFF,0x00,0x3C,0xFF,0xFF,0xFF,0x3F,0xFF,0xFF,0xFF,0x3F,
    0xFF,0xFF,0xFF,0x3F,0xFF,0xFF,0xFF,0x3F,
};

static const uint8_t kTileIcon03[kIconBytes] PROGMEM = {
    0xFF,0xFF,0xFF,0x3F,0xFF,0xFF,0xFF,0x3F,0xFF,0xFF,0xFF,0x3F,0xFF,0xFF,0xFF,0x3F,
    0xFF,0xFF,0xE0,0x3F,0xFF,0x7F,0xE0,0x3F,0xFF,0x3F,0xE0,0x3F,0xFF,0x1F,0xE0,0x3F,
    0xFF,0x0F,0xE0,0x3F,0xFF,0xFF,0xE0,0x3F,0xFF,0xFF,0xE0,0x3F,0xFF,0xFF,0xE0,0x3F,
    0xFF,0xFF,0xE0,0x3F,0xFF,0xFF,0xE0,0x3F,0xFF,0xFF,0xE0,0x3F,0xFF,0xFF,0xE0,0x3F,
    0xFF,0xFF,0xE0,0x3F,0xFF,0xFF,0xE0,0x3F,0x33,0xF9,0xE0,0x3F,0x33,0xF9,0xE0,0x3F,
    0x33,0xF9,0xE0,0x3F,0x33,0xF9,0xE0,0x3F,0x33,0xF9,0xE0,0x3F,0x33,0x09,0x00,0x3E,
    0x43,0x0C,0x00,0x3E,0x43,0x0C,0x00,0x3E,0xFF,0xFF,0xFF,0x3F,0xFF,0xFF,0xFF,0x3F,
    0xFF,0xFF,0xFF,0x3F,0xFF,0xFF,0xFF,0x3F,
};

static const uint8_t kTileIcon04[kIconBytes] PROGMEM = {
    0xFF,0xFF,0xFF,0x3F,0xFF,0x03,0xF0,0x3F,0xFF,0x03,0xF0,0x3F,0xFF,0x03,0xF0,0x3F,
    0xFF,0xFF,0xFF,0x3F,0xFF,0x03,0xF0,0x3F,0xFF,0xFF,0xFF,0x3F,0xFF,0x01,0xF0,0x3F,
    0xFF,0x00,0xE0,0x3F,0xFF,0x04,0xE4,0x3F,0x7F,0x04,0xC4,0x3F,0x1F,0x00,0x80,0x3F,
    0x0F,0xFE,0x0F,0x3F,0x87,0xFF,0x1F,0x3E,0xC7,0xFF,0x7F,0x3C,0xC7,0xFF,0x7F,0x3C,
    0xCF,0xFF,0x7F,0x3C,0x8F,0xFF,0x7F,0x3E,0x9F,0xFF,0x3F,0x3E,0x1F,0xFF,0x1F,0x3F,
    0x3F,0xFC,0x0F,0x3F,0x3F,0xF8,0x87,0x3F,0xFF,0xFF,0xFF,0x3F,0xFF,0xFE,0xEF,0x3F,
    0x7F,0xFE,0xCF,0x3F,0x3F,0x00,0x80,0x3F,0x1F,0x00,0x00,0x3F,0x3F,0x00,0x80,0x3F,
    0x7F,0xFE,0xCF,0x3F,0xFF,0xFE,0xEF,0x3F,
};

static const uint8_t kTileIcon05[kIconBytes] PROGMEM = {
    0x00,0x00,0x00,0x00,0x00,0x00,0x00,0x00,0x00,0x00,0x00,0x00,0x00,0x00,0x00,0x00,
    0x00,0x00,0x00,0x00,0x00,0x00,0x00,0x00,0x00,0x00,0x00,0x00,0x00,0x00,0x00,0x00,
    0x00,0x00,0x00,0x00,0x00,0x00,0x00,0x00,0x00,0x00,0x00,0x00,0x00,0x00,0x00,0x00,
    0x00,0x00,0x00,0x00,0x00,0x00,0x00,0x00,0x00,0x00,0x00,0x00,0x00,0x00,0x00,0x00,
    0x00,0x00,0x00,0x00,0x00,0x00,0x00,0x00,0x00,0x00,0x00,0x00,0x00,0x00,0x00,0x00,
    0x00,0x00,0x00,0x00,0x00,0x00,0x00,0x00,0x00,0x00,0x00,0x00,0x00,0x00,0x00,0x00,
    0x00,0x00,0x00,0x00,0x00,0x00,0x00,0x00,0x00,0x00,0x00,0x00,0x00,0x00,0x00,0x00,
    0x00,0x00,0x00,0x00,0x00,0x00,0x00,0x00,
};
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

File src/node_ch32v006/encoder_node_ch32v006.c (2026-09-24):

#include <ch32v00X.h>
#include <debug.h>
#include <string.h>

#include "protocol_v2.h"

#define AS5600_ADDR 0x36u
#define AS5600_STATUS 0x0Bu
#define AS5600_RAW_ANGLE 0x0Cu
#define TMAG_MANUFACTURER_LSB 0x0Eu
#define TMAG_SENSOR_CONFIG_1 0x02u
#define TMAG_DEVICE_CONFIG_2 0x01u
#define TMAG_X_RESULT 0x12u
#define CAP_AS5600 (1u << 0)
#define CAP_TMAG5273 (1u << 1)
#define CAP_JOYSTICK (1u << 2)
#define CAP_BUTTONS (1u << 3)
#define LOOP_US 50u
#define TICKS_PER_MS (1000u / LOOP_US)
#define SAMPLE_TICKS (2000u / LOOP_US)
#define CRC_LED_TICKS (2000000u / LOOP_US)
#define BUTTON_STAT_MIN_TICKS (200000u / LOOP_US)

static const uint8_t tmag_addresses[] = {0x35u, 0x22u, 0x78u, 0x44u};

static CctrlBusParser parser;
static uint8_t node_id = 0xFF;
static uint8_t node_type = CCTRL_NODE_ENCODER;
static uint8_t enumerated;
static uint8_t encoder_status = CCTRL_ENC_DATA_STALE;
static uint8_t handle_status = CCTRL_HANDLE_DATA_STALE;
static uint8_t handle_buttons;
static uint8_t handle_buttons_down;
static uint8_t handle_button_stat_active;
static uint8_t tmag_address;
static uint16_t raw_angle;
static uint16_t joystick_x;
static uint16_t joystick_y;
static int16_t magnetic_x;
static int16_t magnetic_y;
static int16_t magnetic_z;
static uint32_t ticks;
static uint32_t last_good_tick;
static uint32_t crc_error_until_tick;
static uint32_t handle_button_stat_until_tick;
static volatile uint8_t rx_ring[128];
static volatile uint8_t rx_head;
static volatile uint8_t rx_tail;

static void gpio_init(void);
static void startup_led_test(void);
static void uart_init(void);
static void i2c_init(void);
static void adc_init(void);
static uint16_t adc_read(uint8_t channel);
static uint8_t i2c_read(uint8_t address, uint8_t reg, uint8_t *data,
                        uint8_t length);
static uint8_t i2c_write(uint8_t address, uint8_t reg, uint8_t value);
static void detect_node_type(void);
static void sample_node(void);
static void update_handle_button_stat(void);
static void update_leds(void);
static void process_frame(void);
static void uart_write(const uint8_t *data, uint8_t length);

int main(void) {
  SystemCoreClockUpdate();
  Delay_Init();
  gpio_init();
  startup_led_test();
  uart_init();
  i2c_init();
  adc_init();
  cctrl_bus_parser_reset(&parser);
  Delay_Ms(2);
  detect_node_type();
  sample_node();

  for (;;) {
    while (rx_head != rx_tail) {
      const uint8_t byte = rx_ring[rx_head];
      rx_head = (uint8_t)((rx_head + 1u) & 0x7Fu);
      const int result = cctrl_bus_parser_push(&parser, byte);
      if (result == 1) {
        process_frame();
        cctrl_bus_parser_reset(&parser);
      } else if (result == -1) {
        crc_error_until_tick = ticks + CRC_LED_TICKS;
        cctrl_bus_parser_reset(&parser);
      } else if (result == -2) {
        cctrl_bus_parser_reset(&parser);
      }
    }
    if ((ticks % SAMPLE_TICKS) == 0u) sample_node();
    update_leds();
    ++ticks;
    Delay_Us(LOOP_US);
  }
}

static void gpio_init(void) {
  GPIO_InitTypeDef gpio = {0};
  RCC_PB2PeriphClockCmd(RCC_PB2Periph_GPIOC | RCC_PB2Periph_GPIOD, ENABLE);
  gpio.GPIO_Pin = GPIO_Pin_3 | GPIO_Pin_4;
  gpio.GPIO_Speed = GPIO_Speed_30MHz;
  gpio.GPIO_Mode = GPIO_Mode_Out_PP;
  GPIO_Init(GPIOC, &gpio);
  GPIO_ResetBits(GPIOC, GPIO_Pin_3 | GPIO_Pin_4);

  gpio.GPIO_Pin = GPIO_Pin_6 | GPIO_Pin_7;
  gpio.GPIO_Mode = GPIO_Mode_IPU;
  GPIO_Init(GPIOC, &gpio);

  /* The fitted 5-pin joystick has VCC/GND reversed: S3 closes to 3V3. */
  gpio.GPIO_Pin = GPIO_Pin_5;
  gpio.GPIO_Mode = GPIO_Mode_IPD;
  GPIO_Init(GPIOC, &gpio);
}

static void startup_led_test(void) {
  for (uint8_t i = 0; i < 2; ++i) {
    GPIO_SetBits(GPIOC, GPIO_Pin_3 | GPIO_Pin_4);
    Delay_Ms(140);
    GPIO_ResetBits(GPIOC, GPIO_Pin_3 | GPIO_Pin_4);
    Delay_Ms(140);
  }
}

static void uart_init(void) {
  GPIO_InitTypeDef gpio = {0};
  USART_InitTypeDef uart = {0};
  NVIC_InitTypeDef irq = {0};
  RCC_PB2PeriphClockCmd(RCC_PB2Periph_GPIOD | RCC_PB2Periph_USART1, ENABLE);
  gpio.GPIO_Pin = GPIO_Pin_5;
  gpio.GPIO_Speed = GPIO_Speed_30MHz;
  gpio.GPIO_Mode = GPIO_Mode_AF_PP;
  GPIO_Init(GPIOD, &gpio);
  gpio.GPIO_Pin = GPIO_Pin_6;
  gpio.GPIO_Mode = GPIO_Mode_IN_FLOATING;
  GPIO_Init(GPIOD, &gpio);
  uart.USART_BaudRate = 250000;
  uart.USART_WordLength = USART_WordLength_8b;
  uart.USART_StopBits = USART_StopBits_1;
  uart.USART_Parity = USART_Parity_No;
  uart.USART_HardwareFlowControl = USART_HardwareFlowControl_None;
  uart.USART_Mode = USART_Mode_Rx | USART_Mode_Tx;
  USART_Init(USART1, &uart);
  USART_ITConfig(USART1, USART_IT_RXNE, ENABLE);
  irq.NVIC_IRQChannel = USART1_IRQn;
  irq.NVIC_IRQChannelPreemptionPriority = 1;
  irq.NVIC_IRQChannelSubPriority = 0;
  irq.NVIC_IRQChannelCmd = ENABLE;
  NVIC_Init(&irq);
  USART_Cmd(USART1, ENABLE);
}

static void i2c_init(void) {
  GPIO_InitTypeDef gpio = {0};
  I2C_InitTypeDef i2c = {0};
  RCC_PB2PeriphClockCmd(RCC_PB2Periph_GPIOC, ENABLE);
  RCC_PB1PeriphClockCmd(RCC_PB1Periph_I2C1, ENABLE);
  gpio.GPIO_Pin = GPIO_Pin_1 | GPIO_Pin_2;
  gpio.GPIO_Speed = GPIO_Speed_30MHz;
  gpio.GPIO_Mode = GPIO_Mode_AF_OD;
  GPIO_Init(GPIOC, &gpio);
  i2c.I2C_ClockSpeed = 400000;
  i2c.I2C_Mode = I2C_Mode_I2C;
  i2c.I2C_DutyCycle = I2C_DutyCycle_2;
  i2c.I2C_OwnAddress1 = 0;
  i2c.I2C_Ack = I2C_Ack_Enable;
  i2c.I2C_AcknowledgedAddress = I2C_AcknowledgedAddress_7bit;
  I2C_Init(I2C1, &i2c);
  I2C_Cmd(I2C1, ENABLE);
}

static void adc_init(void) {
  GPIO_InitTypeDef gpio = {0};
  ADC_InitTypeDef adc = {0};
  RCC_PB2PeriphClockCmd(RCC_PB2Periph_GPIOD | RCC_PB2Periph_ADC1, ENABLE);
  RCC_ADCCLKConfig(RCC_PCLK2_Div8);
  gpio.GPIO_Pin = GPIO_Pin_2 | GPIO_Pin_3;
  gpio.GPIO_Mode = GPIO_Mode_AIN;
  GPIO_Init(GPIOD, &gpio);
  ADC_DeInit(ADC1);
  adc.ADC_Mode = ADC_Mode_Independent;
  adc.ADC_ScanConvMode = DISABLE;
  adc.ADC_ContinuousConvMode = DISABLE;
  adc.ADC_ExternalTrigConv = ADC_ExternalTrigConv_None;
  adc.ADC_DataAlign = ADC_DataAlign_Right;
  adc.ADC_NbrOfChannel = 1;
  ADC_Init(ADC1, &adc);
  ADC_Cmd(ADC1, ENABLE);
  ADC_BufferCmd(ADC1, ENABLE);
}

static uint16_t adc_read(uint8_t channel) {
  ADC_RegularChannelConfig(ADC1, channel, 1, ADC_SampleTime_CyclesMode7);
  ADC_SoftwareStartConvCmd(ADC1, ENABLE);
  while (ADC_GetFlagStatus(ADC1, ADC_FLAG_EOC) == RESET) {}
  return ADC_GetConversionValue(ADC1) & 0x0FFFu;
}

static uint8_t i2c_wait(uint32_t event) {
  uint32_t timeout = 30000;
  while (I2C_CheckEvent(I2C1, event) != READY)
    if (--timeout == 0) return 0;
  return 1;
}
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

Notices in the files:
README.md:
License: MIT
